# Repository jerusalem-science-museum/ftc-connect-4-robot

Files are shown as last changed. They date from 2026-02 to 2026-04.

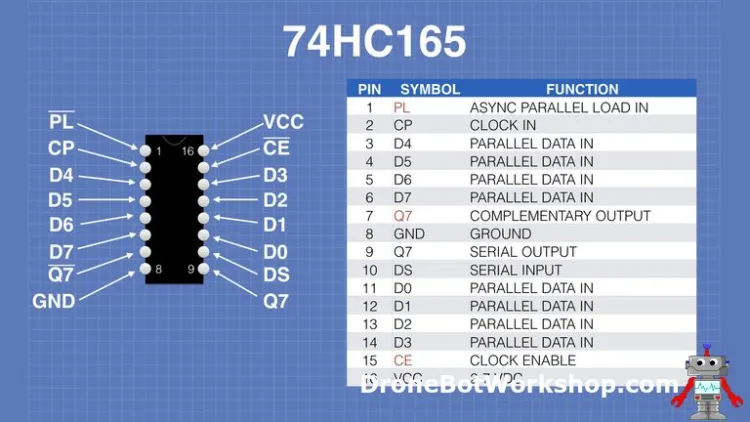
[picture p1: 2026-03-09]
docs/schematics and connections/piso 165.jpeg

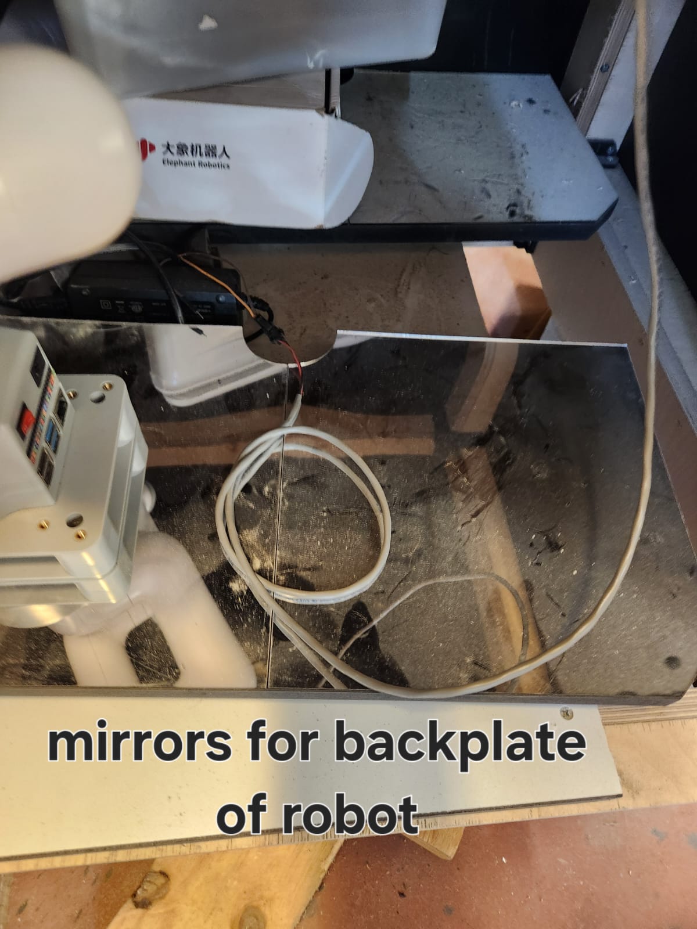
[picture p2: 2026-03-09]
docs/Photos/mirror for robot background.jpg

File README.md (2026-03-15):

# Connect 4 Robot

A robotic Connect 4 game where a MyCobot 280 robot arm plays against a human player. The system uses drop detection via LED strip sensors, automated puck dispensing with solenoids, and AI-powered gameplay.

## System Overview

```
┌───────────────────────────────────┐
│       PC MAIN CONTROLLER          │
│   ┌────────────┬────────────┐     │
│   │   Robot    │   Arduino  │     │
│   │ Interface  │ Interface  │     │
│   └────────────┴────────────┘     │
└─────────────┬──────┬──────────────┘
              │      │
        USB Serial   USB Serial
              │      │
     ┌────────▼─┐ ┌───▼────────────┐
     │  Robot   │ │   Arduino      │
     │  Arm     │ │ - LED Strip    │
     │  (via    │ | - Solenoids    │
     │pymycobot)│ │ - Sensors      |
     │          | | - Robot Pump   |
     └──────────┘ └────────────────┘
```

## Architecture

The system consists of three main controllers:

1. **PC Main Controller** - Orchestrates gameplay, runs AI, manages state
2. **Arduino Controller** - Handles LED strip, solenoid puck release, drop detection sensors, pump activation
3. **MyCobot 280 Robot Arm** - Picks and places pucks (using arduino pump), delivers pucks to player

## Key Components

### Game Logic (`game.py`)
- **Responsibilities**: Orchestrate turns, check win/draw, trigger robot moves
- **Event Handler**: `on_player_drop(column)` - called when Arduino detects puck
- **Flow**: Player drops → Update board → Check win → Calculate AI move → Execute robot → Repeat

### Board (`core/board.py`)
- **Responsibilities**: Store state, validate moves, detect wins
- **Pure Logic**: No hardware dependencies, easily testable
- **API**: `drop_piece()`, `is_valid_move()`, `check_win()`, `is_draw()`, `get_state()`

### AI Engine (`core/ai.py`)
- **Algorithm**: Minimax with alpha-beta pruning
- **Input**: Board state as 2D array
- **Output**: Best column to play (0-6)
- **Configurable**: Search depth adjustable via `config.yaml`

### Arduino Interface (`hardware/arduino.py`)
- **Responsibilities**: Serial communication, command sending, event callbacks
- **Commands**: `RELEASE:<col>`, `LED:[ON/OFF]`, `RESET`, `STATUS`
- **Events**: `DROP:<col>` (puck detected), `READY`, `ERROR:<msg>`
- **Thread Model**: Background listener thread for async event handling

### Robot Interface (`hardware/robot.py`)
- **Wrapper**: Clean API around legacy `ArmInterface.py`
- **Methods**: `place_puck_at_column(col)`, `give_player_puck()`, `move_to_home()`
- **Position Management**: Loads calibrated positions from `positions.json`

### Mock Hardware (`hardware/mock.py`)
- **Purpose**: Enable development/testing without physical hardware
- **Classes**: `MockArduino`, `MockRobot`
- **Usage**: Set `simulation: true` in `config.yaml`

## Setup

### Prerequisites

- **Hardware** (for production use):
  - MyCobot 280 robot arm (M5 Stack version)
  - Arduino with custom PCB (LED strip + solenoid drivers + sensors)
  - USB connections for both
  
- **Software**:
  - Python 3.8+
  - Arduino IDE (for firmware upload)

## How to Play

1. System initializes and robot moves to home position
2. Robot gives yellow puck to player at pickup location
3. Player drops puck in any column (detected by LED strip sensor)
4. PC calculates best move and robot executes (picks red puck, drops in column)
5. Robot returns and gives next yellow puck to player
6. Repeat until someone wins or board is full
7. System displays winner via XXX??? and resets for new game

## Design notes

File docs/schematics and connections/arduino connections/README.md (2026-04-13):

describes pin connections between components that are connected to the arduino.

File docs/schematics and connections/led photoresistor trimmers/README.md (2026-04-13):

# Photoresistor (LDR) trimmer board
A voltage splitter for identifying a voltage drop due to the puck blocking the light from the ledstrip.

can be used in multiple modes:  
1. using a potentiometer (what we did for now)
2. using constant-value resistors

IMPORTANT: the resistance we used for the detection in the end was **10Kohm.**

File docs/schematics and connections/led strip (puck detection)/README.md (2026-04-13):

# led strip for puck detection
Dual use pcb (depending on how and what you connect to it):
1. the leds on the one side that shine constant light, connect directly to 12v.  
2. the photoresistors (LDRs) on the other side that connects to the [trimmers](../led%20photoresistor%20trimmers) for sensing if the puck blocked the light from the leds.  

## General Specs
- total size - 360mmx7mm
- Each slot has pads for 0603, 2835, and TH type components.
- distance between adjacent components (leds/LDRs) - 51mm
- 2.1mm holes for tightening screws (though we just used glue), each 51mm apart.

## Connectors
- 

10 פינים בפסיעה של 1.25 מ"מ בצד הCS אפשר לחבר זוויתי או ניצב (סביר יותר).

פין 1 לפלוס, פין 2 למינוס, פין 3 (עתידי\רזרווה) מתחבר רק לאחד מפיני מולקס 2 פין

2 פינים פסיעה 2.54 (מולקס רגיל)  בקצה הכרטיס . פין אחד לפין 3 של קונקטור 10 פינים ואחד לאדמה – בעריכה עתידית צריך אולי לחבר לאדמה )

כי במידה ומשתמשים בקונקטור ה2 פין לכרטיס עם הלדים. צריך כרגע לגמפר ידנית את חיבור המינוס למולקס 2 פין

לדים מחוברים בשני זוגות בטור עם נגד ושלוש בטור עם נגד. גמפרים ונגדים בצד ה CS.

פלוס משותף לאנודות, מינוס לנגדים.

ערכי הנגדים לא בטוח ה 300 אוהם כמו שכתוב בשרטוט – לזוג לדים צריך נגד גדול יותר מאשר לשלישיה.

פוטוטרנזיסטורים- הפלוסים מחוברים פלוס דרך גמפרים (בצד ה PS) לפלוס. כל מינוס מחובר  בנפרד לפין נפרד בקונקטור בהמשך לנגד PD לאדמה מחוץ לכרטיס.  פינים 4-10 (כולל) בקונקטור.

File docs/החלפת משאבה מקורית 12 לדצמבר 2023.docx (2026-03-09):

12 לדצמבר 2023

המשאבה המקורית התקלקלה – בעיות במגעים\פחמים.

החלפתי למשאבה זעירה 5 וולט דגם Dp- שיש להו יותר מ110 כי יוסי קנה בטעות במקום ברזים חשמליים.

יש כרטיסון קטן המקבל פיקוד 5 וולט ומפעיל גם את המשאבה וגם ברז חשמלי לשחרור – חיבור הצנרת דרך מחבר T.

לא זוכר (וכנראה שכחתי לצלם\לרשום) את לוגיקת העבודה של הככרטיסון אבל נדמה לי שיש ממיר מתח קטן ומיקרו קטן אולי כדי לקבל גם פיקוד ב3.3 וולט מהאספרסיב.

אחרי שהמוצג עבד עם המשאבה החדשה התברר שהיא קצת חלשה מדי כי הדסקיות הצהובות (היותק עבות\כבדות) לא נתפסת טוב לפעמים.

הזמנתי משאבות חדשות ל 12 וולט ול 6 וולט (ינואר 2024 דרך יוסי) ובינתיים חיברתי שלוש משאבות קטנות במקביל עם מחבר X .

צריכת זרם לשלוש המשאבות במקביל (ב5 וולט) כ0.28 אמפר, כ0.09 אמפר למשאבה. בחיבור בקוטביות המקורית (חוט אדום לפלוס) הפיה השואבת היא הקרובה יותר לקצה ולא למרכז המלבן.

קוטר המיות של המשאבה כ3.1 מ"מ השתמשתי בצינור סיליקון מאינפוזיה ישנה של עדן 3/4 להכין טבעות מעבר לצינור סיליקון אקווריום 4/6. כדאי אבל טיפת דבק.

ווטסאפ אמיר לדקל 12 לדצמבר 2023

הכרטיס בסדר, מוציא 5 וולט. המשאבה תקולה ונראה שבעיה במגעים(קומוטטור/"פחמים") פנימיים כי כשקצת לוחצים מבחוץ מתחיל להסתובב. אבל חייבים להחליף כי זו תקלה של סוף אורך חיים בדרך כלל. במיידי יש לי משאבה ל5 וולט אבל הרבה יותר קטנה, צריך לוודא שמספיקה מבחינת קצב שאיבה. בהמשך כדאי להחליף למשאבה אמינה יותר, אבל תצטרך כנראה 12 וולט. יש לך מקור לספק אותו. אם לא והכל עובד על 5 וולט אפשר להכין כרטיסון ממיר קטן. וגם נצטרך כראיס מיתוג אחר. דבר איתי

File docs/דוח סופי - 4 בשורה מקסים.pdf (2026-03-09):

# המחלקה להנדסת מכונות

# פיתוח מוצג אינטראקטיבי המדגים פעולה רובוטית על ידי משחק "ארבע בשורה"

# מאת מקסים מז'ביין

## מנחה אקדמי: ד"ר מחמוד ספדי מנחה מקצועי: ד"ר אמיר בן שלום

## 04/09/2025 י' אלול תשפ"ה

# הצהרה

## העבודה נעשתה בהנחיית ד"ר אמיר בן שלום, בארגון "מוזיאון המדע

ע"ש בלומפילד ירושלים", ובהנחיית ד"ר ספדי מחמוד, עזריאלי מכללה אקדמית להנדסה ירושלים, המחלקה להנדסת מכונות.

## החיבור מציג את עבודתי האישית

ומהווה חלק מהדרישות לקבלת תואר ראשון בהנדסה.

## כל טקסט ו/או תוצאה המבוססים על עבודות מחקר אחרות, מתועדים

בציון המקור המדעי.

## תקציר

הפרויקט עוסק בתיקון מוצג במוזיאון המדע שבו המבקר משחק את משחק הקופסא "ארבע בשורה" מול זרוע רובוטית.

המוצג דורש תיקון מכיוון שהוא השתמש בראייה ממוחשבת לקליטת מצב הלוח, מערכת שכשלה לעיתים קרובות ועשתה את המוצג בלתי שמיש ולכן המוצג הורד מרחבת המוזיאון.

הפרויקט מתמקד בפיתוח מערכת המבוססת על חיישנים אלקטרוניים לקליטת נפילת דסקיות בעמודות הלוח.

הדוח הנוכחי מציג את הפתרון המוצע המבוסס על חיישני אור אלקטרוניים, המאפשרים זיהוי אמין של נפילת הדסקיות בעמודות הלוח. בדוח מוצגים כל השלבים והניסויים: החל מבחירת החיישן המתאים )פוטורזיסטור( וקביעת ערך הנגד במחלק המתח, דרך בחירת צבע LED אופטימלי, ועד פיתוח פרוטוקול תקשורת בינארי ייעודי בין בקר החיישנים למחשב המפעיל את הזרוע. לבסוף מתוארים השיקולים ההנדסיים ואופן ההתקנה הסופי של החיישנים על לוח המשחק.

# תוכן עניינים

תקציר 2 |
.1 מבוא5 |
.2 רקע תיאורטי6 |
.2.1 ארבע בשורה 6 |
.2.2 הזרוע הרובוטית - 5M280 MyCobot6 |
.2.3 חוק אוהם 8 |
.2.4 חוק קירכהוף לזרם - KCL8 |
.2.5 חוק קירכהוף למתח - KVL9 |
.2.6 מחלק מתח9 |
.2.7 מיקרו בקרים - 32ESP & Arduino10 |
.2.8 אוגר זיזה - Register Shift11 |
.2.9 חיישני אור - פוטורזיסטורים12 |
.2.10 ביטים, בייטים וייצוג בינארי14 |
.3 מטרות 15 |
.4 חקר המצב הקיים 16 |
.4.1 המצב הקיים 16 |
.4.2 חקר המצב הקיים - תקלות ובעיות 18 |
.4.3 ניתוח חוזק הזרוע לאימות התקנה אופקית 18 |
.5 מתודולוגיות21 |
.5.1 להישאר עם ראיה ממוחשבת 21 |
.5.2 פתרון אלקטרוני מבוסס חיישנים22 |
.5.3 המתודולוגיה שנבחרה 24 |
.6 יישום ופיתוח הפתרון 24 |
.6.1 חישוב זמן חסימת החיישן על ידי דיסקית נופלת 24 |
.6.2 בחירת הלד המתאים28 |
.6.3 בחירת הנגד המתאים למחלק המתח 31 |
.6.4 שילוב עם המיקרו בקר33 |
.6.5 תכנון פרוטוקול התקשורת 35 |
.6.6 עיצוב התוכנה38 |
.6.7 מידול הפתרון41 |
.7 תוצאות44 |
.8 תכנון מול ביצוע45 |
.9 ביבליוגרפיה46 |
.10 נספחים 47 |
.10.1 תרשים GANTT 47 |
.10.2 תרשים WBS 48 |
.10.3 קוד פרוטוקול התקשורת בC לבניית בייט ההודעה48 | :
.10.4 הקוד בפייתון ליצירת ופיענוח הודעה: 49 |
.10.5 הקוד לשליחת הודעה, והמתנה לאישור בפייתון49 | :

# תוכן איורים

איור #1 - לוח ארבע בשורה6 |
איור #2 - מערכת הקואורדינטות של הזרוע הרובוטית 7 |
איור #3 - מעגל חשמלי פשוט 9 |
איור #4 - דיאגרמת פינים של 165HC74 12 |
איור #5 - מחלק מתח עם פוטורזיסטור13 |
איור #6 - גרף מחלק מתח14 |
איור #7 - מבט איזומטרי של המוצג 16 |
איור #8 - מבט מהצד הפנימי של המוצג 17 |
איור #9 - הזרוע במצב התקנה אופקי, עם מפרקים ממוספרים19 |
איור #10 - הזרוע במצב התקנה אנכי, כאשר המפרק 1J מסובב ב.90° 19 |
איור #11 - דג"ח על הזרוע 21 |
איור #12 - דג"ח של דיסקית בנפילה חופשית25 |
איור -#13 הגדרת פרמטר d של הדיסקית הנופלת 25 |
איור #14 - גרף של זמן נפילת דיסקית עם מהירויות התחלתיות שונות27 |
איור #15 - מערכת הניסוי לבחירת צבע לד28 |
איור #16 - גרף תוצאות ניסוי בחירת צבע לד30 |
איור #17 - השפעת נגד קבוע במחלק מתח31 |
איור #18 - מעגל הניסוי לקביעת ערך נגד קבוע32 |
איור #19 - אוגר זיזה מחובר לבקר הזרוע34 |
איור #20 - דיאגרמת התקשורת בין המחשב לבקרים השונים35 |
איור #21 - דיאגרמה של המודולים של התוכנה38 |
איור #22 - תרשים הזרימה של לוגיקת המוצג 39 |
איור #23 - תיאור מפורט של שלבי התוכנה40 |
איור #24 - מידות הפאנל הקדמי 41 |
איור #25 - שרטוט ממדי רצועת הלדים42 |
איור #26 - שרטוט ממדי רצועת החיישנים 42 |
איור #27 - שרטוט התעלה שבה תותקן רצועת הלדים בצד הפנימי של הפאנל הקדמי 42 |
איור #28 - שרטוט התעלה שבה תותקן רצועת רצועת החיישנים43 |
איור #29 - התקנת הרצועות החיישנים במוצג הסופי44 |

# תוכן טבלאות

טבלה #1 - פרמטרי DH של הזרוע הרובוטית7 |
טבלה #2 - תוצאות ניסוי בחירת צבע לד30 |
טבלה #3 - תוצאות ניסוי בחירת נגד קבוע33 |
טבלה #4 - מבנה בייט התקשורת36 |

## .1 מבוא

הפרויקט נעשה עבור ובשיתוף עם מוזיאון המדע בירושלים - "מוזיאון המדע ע"ש בלומפילד ירושלים".
מוזיאון המדע מציג מגוון מוצגים אינטראקטיביים שנועדו להמחיש עקרונות מדעיים וטכנולוגיים לקהל הרחב, תוך דגש על התנסות אישית וחווייתית. אחד מהמוצגים שנבנו בעבר נועד להדגים עקרון של הפעלת זרוע רובוטית לצורך משחק "ארבע בשורה" מול המשתמש. במוצג זה המשתמש מפיל דסקיות לתוך לוח אנכי, והמערכת אמורה לזהות את מיקום ההפלה, לעדכן את מצב הלוח, ולשלוט בזרוע הרובוטית כדי לדמות שחקן שני ולאתגר את המשתמש.

עם זאת, המוצג המקורי לא תפקד בצורה מספקת, מערכת הזיהוי שהתבססה על ראייה ממוחשבת לא הצליחה לזהות בצורה אמינה את מיקום הדסקיות, ובגלל זה גם לא הצליחה לעשות מהלכים שיאתגרו את המשתמש. בעיות אלו נבעו בין השאר מתנאי תאורה משתנים, צבעי בגדים של המשתמשים, וחוסר עקביות בקריאות החיישנים. כתוצאה מכך המוצג הוסר מהתצוגה עד שיתוכנן מנגנון חדש לזיהוי מיקום הדסקיות של המשתמש.

מטרת פרויקט זה היא להחזיר את המוצג לפעולה על ידי תכנון מנגנון שיקלוט את מיקום הפלת הדיסקית של המשתמש באופן אמין ועקבי, וכתוצאה מכך ייתן אתגר למשתמש, ללא צורך בתחזוקה קבועה או התערבות מפעיל.

הדוח הנוכחי מציג את שלבי הפרויקט מהגדרת הבעיה ועד לפתרון. לאחר פרק המבוא, מובא רקע תיאורטי הכולל את המידע הטכני הדרוש להבנת הפתרון שנבנה. בהמשך מפורטות מטרות הפרויקט, מתודולוגיות שונות שנשקלו לפתרון הבעיה, ותהליך בחירת הפתרון. לאחר מכן מתוארים הניסויים שבוצעו ותוצאותיהם, תהליך היישום של המערכת בפועל, והמסקנות שהוסקו מהתהליך. בסוף הדוח מופיעה רשימת מקורות ונספחים טכניים.

## .2 רקע תיאורטי

## .2.1 ארבע בשורה

ארבע בשורה הינו משחק לוח בין שני שחקנים , שמשוחק על לוח אנכי בעל 7 טורים ו6- שורות. השחקנים לוקחים תורות בהפלת דסקיות אל תוך העמודות במטרה להגיע לרצף של 4 דיסקיות בצבע שלהם. תנאי הניצחון הוא רצף של ארבע דסקיות באלכסון , טור או שורה )בתמונה 1 רואים מצב לוח בו השחקן עם הדיסקיות הצהובות ניצח באמצעות רצף אלכסון(. שוויון קורה כאשר הלוח מתמלא בלי שנוצר רצף של 4 דיסקיות לאף שחקן. ב1988 הוכח שארבע בשורה הוא משחק "פתור", משחק פתור זהו משחק שמכל מצב אפשרי שלו אפשר לחשב את רצף המהלכים המדויק שיוביל לניצחון - זאת אומרת שהשחקן המתחיל תמיד יכול לנצח או להגיע לשוויון, אך אף פעם לא להפסיד )1988 ,Allis).

איור #1 - לוח ארבע בשורה

## .2.2 הזרוע הרובוטית - 5M280 MyCobot

הזרוע הרובוטית שבה יהיה שימוש בפרויקט היא הזרוע 5M280MyCobot, מבית Elephant .Robotics
זוהי זרוע עם 6 דרגות חופש, המופעלת באמצעות בקר מסוג 32ESP, דרך מערכת ה-Stack 5M -המשלבת מעבד, תצוגה וחיבורים מובנים. הזרוע מתקשרת עם המחשב דרך USB, ומופעלת ע"י שפת התכנות פייתון. אחת המגבלות של המערכת היא קצב התקשורת הנמוך יחסית, הנובע ממעבר בין מספר שכבות תקשורת )כולל פרוטוקולים פנימיים של USB, תרגום פקודות, ועיבוד בפייתון(, דבר המגביל את זמן התגובה של הזרוע לבקשות חיצוניות - עובדה שהתגלתה בניסויים שיצויינו בהמשך הדוח.

הזרוע מסוגלת להרים עד 250 גרם, ורדיוס עבודה של mm.280 לצורך שליטה מדויקת במיקום קצה הזרוע, נעשה שימוש בפרמטרי DH) Hartenberg-Denavit) שמתארים את הגיאומטריה של הזרוע ואת יחסי המיקום בין כל מפרק. פרמטרי הDH של הרובוט נתונים בתמונה .#2
חברת Robotics Elephant מציע ספריות פייתון בכדי לשלוט בזרוע, הכוללות פונקציות לחישוב קינמטיקה הפוכה, המאפשרות לחשב את ערכי הזוויות של כל אחד מהמנועים כדי שקצה הזרוע יגיע לנקודה הרצויה במרחב, תוך התחשבות במגבלות מכניות, מגבלות מומנט, והימנעות מהתנגשות עצמית.
)Elephant Robotics, 2021(

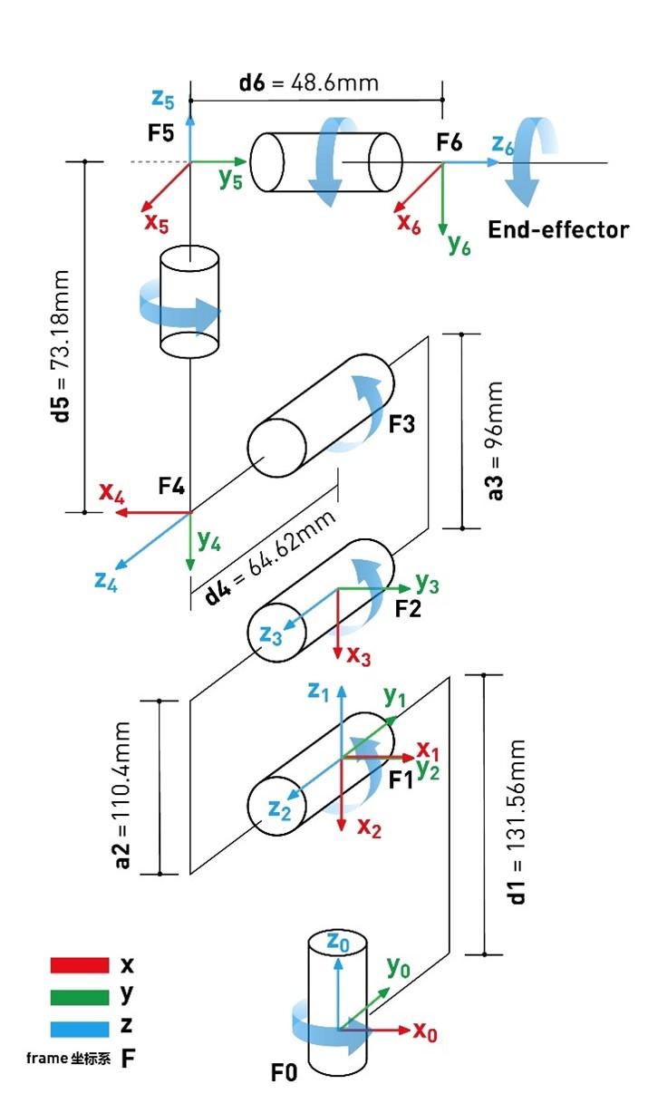
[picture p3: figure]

איור #2 - מערכת הקואורדינטות של הזרוע הרובוטית

| α [DEG] | A [mm] | D [mm] | θ [DEG]
1 | 0 | 0 | 131.56 | θ 0
2 | 90 | 0 | 0 | θ 1
3 | 0 | -110.4 | 0 | θ 2
4 | 0 | -96 | 64.62 | θ 3
5 | 0 | 0 | 73.18 | θ 4
6 | -90 | 0 | 48.6 | θ 5

טבלה #1 - פרמטרי DH של הזרוע הרובוטית

## .2.3 חוק אוהם

חוק אוהם הוא אחד מחוקי היסוד בחשמל ובאלקטרוניקה, והוא מתאר את הקשר בין המתח, הזרם, וההתנגדות במעגל ורכיב חשמלי. חוק אוהם מראה את הקשר הלינארי הקיים בין המתח, לזרם וההתנגדות:

כאשר:
V - מתח, נמדד בוולט ]V]
I - זרם, נמדד באמפר ]A]
R - התנגדות, נמדד באוהם ]Ω]

בחוק אוהם שימוש נרחב במעגלים חשמלים בכדי לקבוע את הפרמטרים השונים הנדרשים להפעלת רכיבים, כגון זרם לנורת לד, או התנגדות כדי להגביל את המתח על רכיב מסויים.

## .2.4 חוק קירכהוף לזרם - KCL

חוק קירכהוף לזרם הידוע גם כ"חוק הראשון של קירכהוף", מתאר את עקרון שימור המטען החשמלי במעגלים חשמליים. החוק קובע כי סכום הזרמים הנכנסים לצומת במעגל חשמלי שווים לסכום הזרמים היוצאים ממנה - לא קורה איבוד של זרם.

)2.4.1(

k=1

n
∑ I

k = 0

כאשר מסתכלים על צומת במעגל חשמלי: - הזרם על ענף ה-k בצומת.
k
n - מספר הענפים בצומת.

נהוג לקבוע את כיוון הזרמים בתחילת הניתוח של המעגל החשמלי ובמקרה של זרמים שליליים סימן שהכיוון הראשוני היה הפוך.

V = RI | )2.3.1(

## .2.5 חוק קירכהוף למתח - KVL

חוק קירכהוף למתח הידוע גם כ"חוק השני של קירכהוף", מתאר עקרון בסיסי במעגלים חשמלים.החוק קובע כי סכום כל המתחים בלולאה סגורה במעגל חשמלי הוא לאפס. חוק זה מבטא את עיקרון שימור האנרגיה במעגל חשמלי.

)2.5.1(

k=1

n
∑ V

k = 0

כאשר מסתכלים על לולאה סגורה במעגל חשמלי: - המתח על הרכיב ה-k בלולאה.
k
n - מספר הרכיבים בלולאה.

## .2.6 מחלק מתח

מחלק מתח הוא כלי בסיסי לניתוח במעגלים חשמליים, המאפשר לחשב את המתח על פני רכיב מסוים, או לחלופין - לייצר מתח נמוך יותר מתוך מתח כניסה נתון. השיטה מבוססת על חיבור שני נגדים או יותר בטור, כך שהמתח מתפלג ביניהם בהתאם לערכם. ניקח את המעגל הפשוט המתואר באיור :3

איור #3 - מעגל חשמלי פשוט

מתוך חוק קירכהוף הראשון, במעגל טורי הזרם הנופל על כל הרכיבים זהה כלומר הזרם על כל אחד מהנגדים זהה, ומחוק קירכהוף השני סכום המתחים על פני הרכיבים במעגל סגור שווה למתח המקור.
באמצעות חוקי קירכהוף וחוק אוהם אפשר להראות שבמעגל טורי ההתנגדות הכוללת היא סכום הנגדים במעגל:

∑ V= V

in − V

1 − V

2 = 0 ⇒ V

in = V

1 + V
2

⇒ IR

total = IR

1 + IR
2

⇒ R

total = R

1 + R
2

ולכן בשילוב עם חוק אוהם על המעגל הכולל:

V

in = R
total

I = (R

1 + R
2

) · I ⇒ I =

V
in
R

1+R
2
ואם נפעיל את חוק אוהם שוב רק על נגד :1

V

1 = IR
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
קיבלנו ביטוי כללי למחלק מתח עבור שני נגדים, אפשר להכליל זאת עבור כל מספר של נגדים בטור:

)2.6.1(

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
כאשר:
- המתח על רכיב n.
n
- ההתנגדות של רכיב n.
n
- מקור המתח.
in
k - מספר הרכיבים במעגל

## .2.7 מיקרו בקרים - 32ESP & Arduino

מיקרו-בקר הוא רכיב אלקטרוני הכולל על גבי שבב יחיד מעבד, זיכרון, וממשק של קלט ופלט. מיקרו בקרים משמשים לשליטה על מערכות משובצות מחשב - מערכות הפועלות בצורה אוטונומית כחלק ממכשירים פיזיים.
משתמשים במיקרו בקרים בשביל מספר דברים: .1 לקלוט קלט ממספר חיישנים למיניהם כפתורים, או רכיבים אנלוגים. .2 לעבד מידע חיצוני שנקרא דרך החיישנים לפי תוכנה שהוטענה בו מראש. .3 להפעיל רכיבים חיצונים המחוברים אליו כגון מנועים, לדים ותצוגות. יש שימוש רב במיקרו בקרים בפרוייקטים הדורשים שילוב מסויים של תוכנה עם חומרה.

Arduino היא פלטפורמה לפיתוח מערכות משובצות והתכנות בה מתבצע דרך שימוש בשפת C. לוח הארדואינו שיהיה בו שימוש בפרויקט הוא מסוג UNO Arduino.

32ESP הוא מיקרו בקר מתקדם, המשמש כיחידת העיבוד המרכזית של הזרוע הרובוטית, וביצוע החישובים הדרושים.
ה־32ESP משולב בתוך הזרוע כחלק מפלטפורמת ה-Stack 5M שהיא פלטפורמה מודולריות הכוללת מסך ממשקי תקשורת וחיבורים נוחים לרכיבים חיצוניים המייעלת את העבודה עם הבקר. לפי הקושחה הקיימת על הבקר, התכנות בו נעשה דרך שפת פייתון, שפה זו מאפשרת פיתוח מהיר ונוח לעומת C, אך היא גם גורמת לעומס עיבוד ולהאטה בקצב התקשורת עם הבקר, במיוחד כאשר יש צורך בעיבוד נתונים בזמן אמת.

בארדואינו וב32ESP נעשה שימוש בפינים דיגיטלים ואנלוגים לחיבור חיישנים ורכיבים שונים. הפינים הדיגיטליים מזהים שני מצבים בלבד - HIGH ו-LOW, כאשר ההבחנה נקבעת לפי המתח הפועל על הפין.
עבור לוחות ארדואינו מתח הסף לHIGH הוא V,3 ועבור לוחות 32ESP מתח הסף הוא כV.2.475 )ARDUINO, 2024) (Espressif Systems, 2016(

## .2.8 אוגר זיזה - Register Shift

בפרויקט נעשה שימוש במספר רב של חיישנים ורכיבים, אך מספר הפינים לחיבור אותם חיישנים ורכיבים הזמינים על גבי הבקרים מוגבל. כדי להרחיב את מספר הקלטים והפלטים על הבקר נעשה שימוש ברכיבי Register Shift או אוגרי זיזה, המאפשרים תקשורת טורית)או מקבילית( עם רכיבים מרובים תוך שימוש במספר קטן של פינים. אוגר זיזה הוא רכיב דיגיטלי המאפשר המרה של מידע טורי למקבילי, ומקבילי לטורי, והם ניתנים לשרשור זה עם זה בשביל הרחבה בלתי מוגבלת.

קיימים שני סוגים של אוגרי זיזה:

: | ממקבילי | טורי | קלט - Parallel in serial out .1
register Shift זה )מסוג 165HC74 )משמש לקריאת מספר חיישנים המחוברים לקווי הקלט המקבילים של רכיב )רגליים H-A, בתמונה #4(. ברגע שניתנת פקודת טעינה )ברגל 1(, הרכיב לוכד את הערכים מכל הקווים H-A, ואז משדר אותם זה אחר זה עם כל הפעלת )פולס( השעון )רגל 2( דרך קו אחד )רגל 9(.

באופן זה ניתן לקרוא 8 חיישנים דרך פין אחד בלבד, במקום 8 פיני קלט נפרדים בבקר. )Texas Instruments, 2015(

איור #4 - דיאגרמת פינים של 165HC74

: | מטורי | מקבילי | פלט - Serial In Parallel out .2
register Shift זה )מסוג 595HC74), דומה לאוגר הזיזה הטורי אך בכיוון ההפוך: הוא מקבל מידע טורי )סדרה של ביטים( דרך כניסה אחת, וממיר אותו לפלט מקבילי על פני 8 יציאות.
באופן זה ניתן להפעיל מספר רב של מנועים, סולנואידים או רכיבים אחרים תוך שימוש במספר מצומצם של פינים בבקר. )Texas Instruments, 2021(

## .2.9 חיישני אור - פוטורזיסטורים

פוטורזיסטור הוא חיישן פסיבי המשנה את התנגדותו בהתאם לכמות האור הפוגעות בו, בניגוד לנגד משתנה מכני )פוטנציומטר(, שינוי ההתנגדות של הפוטורזיסטור מתבצע באופן אוטומטי בהתאם לתנאי הסביבה.

כאשר עוצמת האור גבוהה - התנגדות החיישן יורדת ושואפת לאפס. כאשר עוצמת האור נמוכה התנגדות החיישן עולה מאוד )עד לאזור הMΩ). התנהגות זו מאפשרת קריאת תנאי תאורה בסביבה. דרך נפוצה לעבוד עם פוטורזיסטור היא באמצעות שימוש מחלק מתח, ומדידת המתח הנופל עליו, על ידי התקנת החיישן בטור עם נגד קבוע.

איור #5 - מחלק מתח עם פוטורזיסטור

במערכת המתוארת באיור 5 הפוטורזיסטור מסומן בRp, והמתח הנופל עליו, על פי עקרון מחלק המתח )נוסחה 2.6.1( הוא:

V

Rp =

R
p
R

1+R
p
- V
in

אפשר לראות שככול שנופל יותר אור על החיישן התנגדותו תרד ותשאף לאפס, מה שיגרום לרוב המתח ליפול על 1R ולאיפוס המתח על פני החיישן. לחלופין אם אין הרבה אור, התנגדות החיישן תגדל מה שיגרור מתח יותר גבוה על הרכיב, והוא יקבל את רוב מתח הספק.
אפשר לראות בגרף המצורף איך המתח על פני הפוטורזיסטור משתנה עם ההתנגדות שלו, הגרף מתאר מחלק מתח עם מקור מתח של V,5 ונגד קבוע עם ערך של kΩ,2 כאשר ציר X זה התנגדות הפוטורזיסטור, וציר Y המתח עליו.

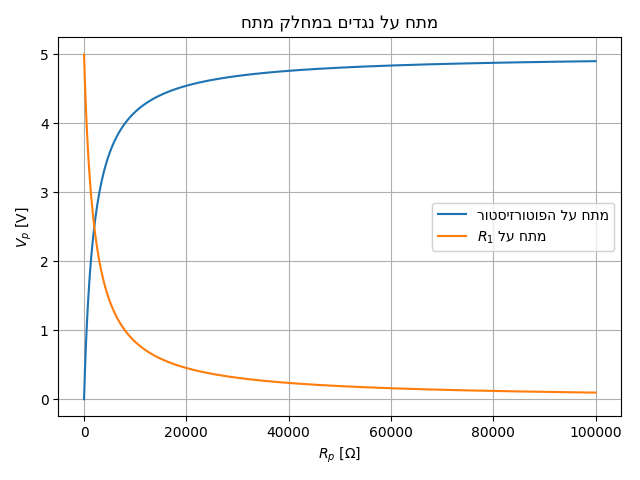
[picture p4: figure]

איור #6 - גרף מחלק מתח

מהגרף אפשר לראות שככול שההתנגדות של הפוטורזיסטור עולה )החיישן מקבל פחות אור(, המתח הנופל עליו שואף ל-V,5 ולהפך - ככל שהחיישן מקבל פחות אור, ההתנגדות עליו יורדת, ולכן המתח עליו מתקרב לאפס, ובנוסף על פי חוק קירכהוף למתח אפשר גם לראות שהמתח על הנגד השני תמיד משלים את סכום המתחים למתח הכניסה של V.5

## .2.10 ביטים, בייטים וייצוג בינארי

במערכות דיגיטליות מידע מיוצג באמצעות מצבים חשמליים: מתח גבוה )1( ומתח נמוך )0(, מצב כזה נקרא ביט )סיבית(, ומערכת המבוססת על ביטים נקראת מערכת בינארית.

כאשר יש קבוצת ביטים ביחד מתקבל מספר בבסיס ,2 שבו המיקום של כל ספרה )0/1( מייצג את החזקה של 2 שמוסיפים לערך הסופי על פי הנוסחה הבאה:

Val

10 =
i=0

n−1
∑ b
i
- 2

i

כאשר:
n = מספר הספרות במספר הבינארי. i = מיקום הספרה במספר הבינארי. bi = הספרה במספר הבינארי במיקום ה-i. 10Val = המספר בבסיס 10 )דצימלי(.

לדוגמא:

(1101)

2 = 1 · 2

3
+ 1 · 2

2
+ 0 · 2

1
+ 1 · 2

0 = (13)
10

צירוף של 8 ביטים יוצר בייט )256 מצבים אפשריים(, זהו גודל המידע המינימלי שבו מחשבים קוראים וכותבים לזיכרון, וכן יחידת-הבסיס ברוב פרוטוקולי התקשורת.

## .3 מטרות

המטרות הממוקדות של הפרויקט הן: .1 פיתוח מנגנון זיהוי אמין למיקום הפלת הדיסקית של המשתמש, שלא תלוי בגורמים חיצונים, ומהווה תחליף מלא למנגנון הראיה הממוחשבת הקיים. .2 בחירה ותכנון נכון של מערכת החיישנים, הכולל מיקום התקנה מתאים, ורכיבים מתאימים כדי להשיג את הנאמר בנקודה .1 .3 כתיבת תוכנה של הבקר שתיקח את כל המידע מהחיישנים בזמן אמת, ותשתמש בו כבסיס לאלגוריתם שיריץ את המשחק.
.4 אינטגרציה מלאה בין המערכת החדשה לישנה באופן כזה שיראה שהפתרון החדש היה הפתרון המקורי.
.5 הבטחת אמינות גבוה של המוצג, שלא יכשל או ידרוש מעורבות מפעיל, במשך מאות השעות שיעבוד במוזיאון באופן רציף ויהיה חשוף למבקרי המוזיאון. .6 יישום אלגוריתם משחק שיאתגר את המשתמש, וינצח את המשתמש או לפחות יגיע תמיד לשוויון, ויעניק חוויית אתגר אמיתית.

ממדי ההצלחה למטרות אלה הינן: .1 התוכנה תדע בכל רגע נתון, באמינות של 100% את מצב הלוח בפני המשתמש - סממן שהחיישנים עובדים והמערכת החדשה הוטמעה היטב עם המערכת הישנה. .2 הפעלה של המוצג במשך עשרות שעות ללא התערבות מפעיל וללא זמני השבתה. .3 הזרוע הרובוטית תמיד מנצחת או משיגה שוויון מול המשתמש, סימן לכך שהאלגוריתם יציב ואפקטיבי.

## .4 חקר המצב הקיים

## .4.1 המצב הקיים

בחקר המצב הקיים נתמקד באופן פעולת המוצג לפני תחילת הפרויקט, ולאחר מכן ננתח את הבעיות הקיימות בו.

ניתן לפרק את פעולת המוצג לשלושה חלקים עיקריים:
- הבאת דיסקית למשתמש
- מיון דיסקיות בסוף המשחק
- התוכנה השולטת
לשם הבנה קלה יותר של הפרק, מצורף באיור #7 שרטוט המוצג.

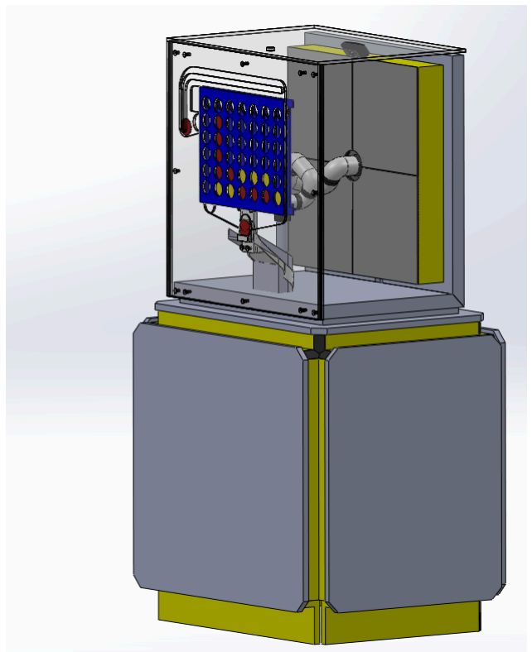
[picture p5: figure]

איור #7 - מבט איזומטרי של המוצג בבסיס אזור המשחק קיים בנק דיסקיות בשני צבעים, אחד לרובוט ואחד למשתמש, כאשר הרובוט מרים דסקית באמצעות משאבת ואקום.

אם התור העכשווי שייך לרובוט הזרוע מפילה את הדיסקית לאחד מ7- העמודות בלוח דרך חורים בצד הפנימי של המוצג. אם התור העכשווי שייך למשתמש אז הזרוע מפילה את הדיסקית לתוך תעלה עליונה שממנה המשתמש גורר את הדיסקית באמצעות האצבע דרך תעלה העוברת מעל שבעת הטורים ומפיל את הדיסקית בעמודה הרצויה, כפי שאפשר לראות באיור .#8

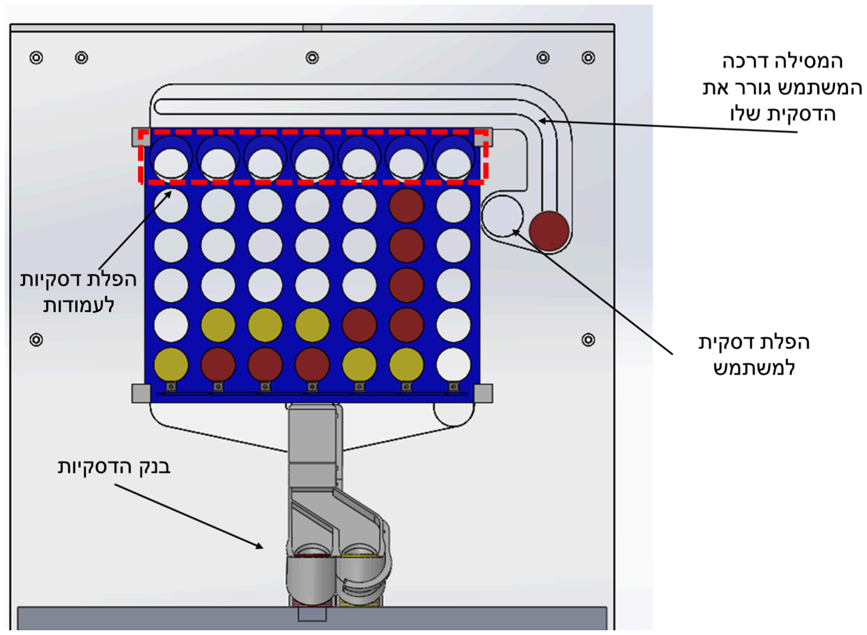
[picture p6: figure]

איור #8 - מבט מהצד הפנימי של המוצג

כדי להשאיר את הדיסקיות במקום קיימים סולנואידים בבסיס כל עמודה המחזיקים את עמודת הדסקיות מעליה, בשביל מיון הדסקיות בסוף המשחק הסולנואידים נפתחים בזה אחר זה ומפילים את הדיסקיות אל מסילה.
במסילה קיים חריץ בעובי 3.5 מ"מ: דיסקיות האדומות יש עובי של 3 מ"מ ולכן הן נופלות דרך החריץ ומנותבות למאגר האדום. דיסקיות הצהובות יש עובי של 4 מ"מ, הן לא מסוגלות לעבור בחריץ ולכן ממשיכות במסילה עד שמגיעות למאגר הצהוב, כפי שאפשר לראות באיור .#8

לצורך קליטת מצב הלוח נעשה שימוש בראייה ממוחשבת. בכל אחת מארבע פינות הלוח מודבק סמן Aruco. מצלמת רשת מצלמת את הלוח בזמן אמת, והסממנים משמשים כנקודות עיגון לזיהוי גבולות הלוח. אלגוריתם עיבוד תמונה מזהה את הדיסקיות בתוך אזור המשחק, מעדכן את מצב הלוח בזיכרון, ומחשב את מהלכי המשחק. האלגוריתם שמשחק מול המשתמש מבוסס על מודל פשוט של למידת מכונה, ונועד לייצר אתגר מסוים לשחקן האנושי.

למיקרו בקר של הזרוע מחובר באופן ישיר אוגר זיזה מסוג 595HC74 בכדי לשלוט בשבעת הסולנואידים,מחוברת המשאבה לשליטה על הואקום, ומחובר הכפתור שמתחיל את המשחק.

## .4.2 חקר המצב הקיים - תקלות ובעיות

רכיבי ההרמה, ההפלה והמיון של הדסקיות פעלו באופן אמין ויציב לאורך זמן. לעומתם, מערכת זיהוי מצב הלוח, שהתבססה על ראייה ממוחשבת כשלה בזיהוי עקבי ואמין של מהלכי המשתמש.

מערכת הזיהוי לא פעלה באופן מדויק. היא הייתה רגישה מאוד לשינויים בתנאי תאורה, ולצבעי בגדים של המשתמשים )במיוחד כאשר צבע הבגד היה דומה לצבע הדיסקית(. כתוצאה מכך נוצרו זיהויים שגויים או חוסר זיהוי כלל.

בנוסף אלגוריתם המשחק לא יצר חוויית אתגר אמיתית, ככל הנראה משתי סיבות:
- הוא מבוסס על מודל פשוט של למידת מכונה, ללא עומק אסטרטגי.
- הוא עבד על סמך נתונים לא מדויקים מהזיהוי החזותי.

בעקבות ליקויים אלה, המוצג הוסר מרחבת התצוגה והועבר לאחסון, עד לפיתוח פתרון חלופי. לא קיימים נתונים מדויקים על אחוזי הכשלונות, אך ידוע שהאמינות לא הגיעה ל־,100% ולכן המוצג לא נמצא מתאים להצגה במצבו הקיים.

## .4.3 ניתוח חוזק הזרוע לאימות התקנה אופקית

הזרוע הרובוטית נועדה לעבוד באופן אנכי, כך שהבסיס עומד על גבי משטח אופקי. במוצג המוזיאון הזרוע מותקנת באופן אופקי כך שהבסיס מותקן על גבי קיר אנכי והזרוע יוצאת ממנו באופן אופקי. התקנה זו מוסיפה כוחות ומאמצים שהיצרן לא בהכרח לקח בחשבון כאשר הוא אמר שהזרוע מסוגלת להרים 250 גרם, ויש אפשרות שהמנועים שהייצרן בחר לא יעמדו בעומסים החדשים המתקבלים להתקנה אופקית.

בזרוע קיימים שישה מפרקים )5J0-J), כאשר כל מנוע תומך במשקלו העצמי של הזרוע ובמשקל המנועים שמעליו. כפי שניתן לראות בתמונות #9 ו,#10- המצב הגיאומטרי שבו הזרוע מותקנת אופקית זהה לחלוטין למצב שבו הזרוע מותקנת אנכית והמפרק הראשון )1J )מסובב ב.90°- במקרה זה, המפרקים 5J1-J נמצאים באותם מיקומים יחסית לכבידה, ולכן חווים את אותם מומנטים ומאמצים בדיוק.

מכאן ניתן להסיק כי עבור המפרקים 5J1-J אין שינוי בעומסים, והתקנה אופקית לא יוצרת מאמץ נוסף בהשוואה למצב האנכי שתוכנן על ידי היצרן. לכן, אם היצרן מציין שהזרוע יכולה להרים עד 250 גרם מכל מצב תנועה אפשרי הנחה זו נותרת תקפה גם עבור התקנה אופקית, כל עוד הכוונה היא לעומסים על מפרקים 5J1-J.

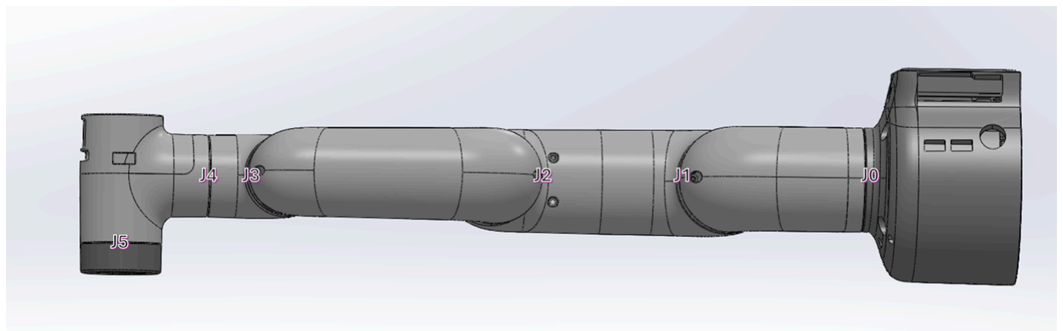
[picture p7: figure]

איור #9 - הזרוע במצב התקנה אופקי, עם מפרקים ממוספרים

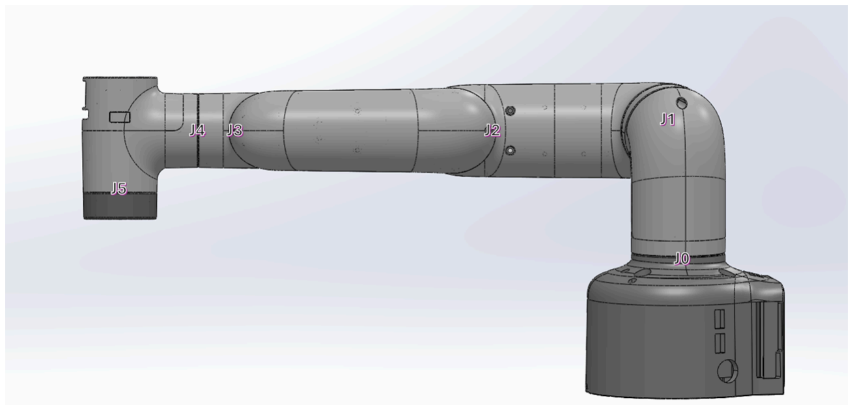
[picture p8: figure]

איור #10 - הזרוע במצב התקנה אנכי, כאשר המפרק 1J מסובב ב.90°

לעומת זאת, מפרק הבסיס )0J )הוא החריג, בתצורה האנכית הוא רק מסובב את הזרוע במישור אופקי, אך בתצורה האופקית הוא נדרש לשאת את משקל הזרוע כולה, ולכן יכולים להיווצר מאמצים שונים בהשוואה להתקנה תקנית, לכן כאשר ננתח את המאמצים על הזרוע, נבדוק רק במפרק הבסיס 0J.

לשם הניתוח של הזרוע הזרוע הרובוטית נדרש לעשות מספר השערות:
- מכיוון שהזרוע היא מערכת דינמית, מרכז הכובד משתנה בהתאם לזוויות הפרקים השונים, לשם הקלת הניתוח ניקח את המצב המחמיר ביותר בו מרכז הכובד הכי רחוק מבסיס הזרוע, ובזמן שפועל מומנט מקסימלי מהמשקל בסוף הזרוע על מנוע הבסיס, ואם הזרוע תחזיק במצב זה, היא תחזיק בכל מצב אחר.
- משקל הזרוע כולה 850 גרם, אך אנחנו לא רוצים את משקל הזרוע כולה, רק ממפרק 1J והלאה, לאחר פירוק הזרוע ושקילתה רק ממפרק 1J נמצא שהמשקל העצמי של חלק זה הוא 515 גרם.
- משקל הדיסקית הכבדה ביותר שהזרוע תרים הוא 8 גרם, נקח מקדם ביטחון של 12 )בכדי לכלול גם את ראש ואקום המותקן( ונבדוק את ביצועי הזרוע עבור משקל של 96 גרם.
מנוע הבסיס המותקן הוא מנוע מסוג D-15LX, המסוגל להפעיל מומנט מקסימלי של Nm/1.91kgcm,19.5 כפי שמתואר במדריך היצרן בעמוד 94 )2021 ,Robotics Elephant).

מומנט המקסימלי על מנוע הבסיס מתקבל כאשר מפרק 1J ו0-J מסובבים ב90- מעלות, ושאר המפרקים ב0- מעלות.
מכאן, הדג"ח על הזרוע:

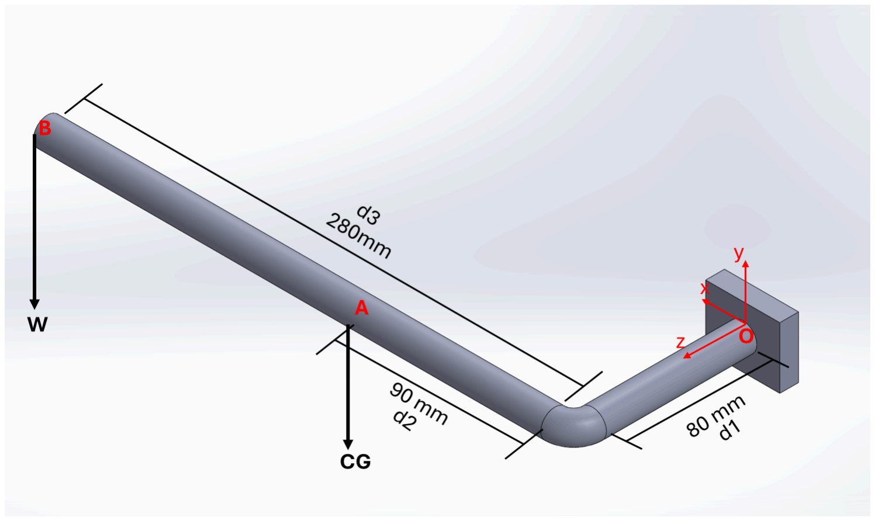
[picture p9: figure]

איור #11 - דג"ח על הזרוע

CG = 0. 515kg * 9. 81m/s

2 = 5. 05N

W = 0. 096kg * 9. 81m/s

2 = 0. 94N

הריאקציות בבסיס )נק' O):

∑ F

x = 0 ⇒ R

x = 0

∑ F

y =− W − CG + R
y

⇒ R

y = W + CG = 5. 99N

∑ F

z = 0 ⇒ R

z = 0

חישוב מומנטים בבסיס )נק' O):

Mx = 0. 479 Nm

M

y = 0 Nm

Mz = 0. 717Nm

המנוע מסוגל להפעיל מומנט בציר z של Nm,1.91 מהחישובים אנו רואים שהמומנט הפועל על המנוע בהתקנה אופקית הינו Nm,0.717 לכן המנוע יתפקד היטב במצב אופקי.

## .5 מתודולוגיות

לצורך פיתוח מנגנון חדש לזיהוי מיקום הפלת הדיסקית במשחק "ארבע בשורה", נבחנו שתי מתודולוגיות עיקריות: המשך עבודה עם מערכת הראייה הממוחשבת הקיימת, או פיתוח מערכת זיהוי אלקטרונית חדשה מבוססת חיישנים.

## .5.1 להישאר עם ראיה ממוחשבת

גישה זו מתבססת על המערכת המקורית שהייתה בשימוש במוצג, הכוללת מצלמה שמצלמת את הלוח בזמן אמת ואלגוריתם המזהה את מצב הדסקיות באמצעות עיבוד תמונה,לטיפול בכשלים הקיימים בפתרון הנוכחי הוצעו מספר פתרונות:
- הוספת מקורות תאורה חיצוניים לשיפור תנאי התאורה.

- הוספת סממן ייחודי על כל דיסקית )42 בסה"כ(, כדי להוריד את משתנה הצבע מהבעיה, ובכך לשלול את הבעיה של הביגוד של המשתמש.
- החלפת האלגוריתם הקיים )מבוסס רשת עצבית( באלגוריתם דטרמיניסטי.

היתרונות בשיטה זו:
- אפשר לעבוד עם המערכת הקיימת מבלי לשנות באופן מהותי את אופן עבודת המוצג.
- דרישה מועטה לשינויים מבניים.
- מאפשר ניטור מלא של מצב הלוח בעזרת רכיב אחד - המצלמה. החסרונות בשיטה זו:
- סממנים על הדסקיות עלולים להתבלות ולהוות 42 נקודות כשל.
- הוספת תאורה מלאכותית עלולה לפגוע בנראות ובחוויה של המשתמש.
- סביבת המוזיאון דינמית, ולכן לא נוכל לשלוט בכל המשתנים שראיה ממוחשבת דורשת כדי להגיע לביצועי אמינות גבוהים.
- מניסיון המוזיאון בראיה ממוחשבת, המוזיאון לא רוצה להישאר עם פתרון זה ורוצה לתכנן פתרון חלופי.

## .5.2 פתרון אלקטרוני מבוסס חיישנים

בגישה זו נבחנה תכנון של מערכת חדשה לזיהוי נפילת הדסקיות, המבוססת על חיישנים אופטיים פיזיים. נבחנו שלושה סוגי חיישנים:

.1 חיישנים אופטים על בסיס החזרה

במערכת זו לד אינפרא־אדום משדר אור לעבר הדיסקית, ופוטורזיסטור סמוך מודד את עוצמת ההחזר. כאשר דסקית נופלת, היא משנה את כמות האור החוזר, וכך ניתן לזהות את נוכחותה. בשיטה זו יהיה לנו חיישן אחד על כל אחת מ7- העמודות בלוח המשחק. היתרונות של חיישן זה:
- קומפקטי - הלד והחיישן נמצאים על אותו לוח.
- לא דורש התקנה מדוייקת.
- אמינות גבוהה.
- התקנה פשוטה בצד אחד בלבד של העמודה. החסרונות של חיישן זה:
- מושפע מצבע הדיסקית, ותוואי פני השטח שלה )בליעת האור, פיזור האור(.

כאשר נעשתה בדיקה עם הדיסקיות הקיימות במוצג התגלה שהן שקופות לאינפרא־אדום, ולכן לא מחזירות את אור החיישן בכלל. זוהי מגבלה קריטית שפוסלת את הפתרון הזה לחלוטין בתצורתו המקורית. )עובדה זו התגלתה בניסוי מהיר של צילום הדסקית באמצעות מצלמה טלפונית שמראה את האור האינפרא-אדום עובר דרכה, לאחר שבדיקות עם החיישן הראו שהוא לא מזהה את הדסקית(.

Time Of Flight - TOF | חיישני | .2

חיישני TOF הם חיישנים מבוססי לייזר המודדים את זמן ההחזר של האור לצורך חישוב מרחק מהאובייקט, בשיטה זו יהיה קיים רק חיישן אחד שיהיה מותקן באופן כזה שקרן הלייזר ממנו חותכת את כל 7 העמודות, ואז כאשר נופלת דיסקית היא תחתוך את קרן הלייזר וחישוב המרחק ייתן לנו את העמודה שבה אירע החיתוך.
יתרונות של חיישן זה:
- התקנה של חיישן יחיד
חסרונות של חיישן זה:
- דורש יישור מוקפד וקליברציה תכופה.
- רוחב קרן רחב מדי שאינו מאפשר להבחין בין עמודות סמוכות.

שיטה זו נפסלה בעקבות ניסיון קודם של המוזיאון שהעיד שלמקרה הספציפי של בעיה זו, תפקוד החיישן לא יביא תוצאות מספקות, והוא לא מתאים לפתרון שמחפשים.

.3 חיישנים אופטים על בסיס העברה

חיישנים אלה עובדים על עיקרון שיש לד המותקן אל מול חיישן אור )כמו פוטורזיסטור(, וכאשר עצם מסוים מגיע בין הלד לחיישן אור וחוסם אותו, המתח על חיישן האור משתנה ולפי קריאת המתח עליו אפשר לדעת אם קרתה חסימה. בשיטה זו יהיה לנו זוג לד-חיישן בכל אחת מ7- העמודות בלוח המשחק.
יתרונות שיטה זו:
- לא תלוי בתוואי שטח הדסקית, או בצבע שלה - עובד עם הדסקיות הקיימות.
- אמינות גבוהה.
חסרונות השיטה:
- דורש התקנה מדויקת של רכיבים משני צידי כל עמודה.

- מחייב שינוי במבנה הפיזי של המוצג.

## .5.3 המתודולוגיה שנבחרה

לאחר בחינה של כל האפשרויות של לגשת לבעיה, נבחר הפתרון של פתרון אלקטרוני מבוסס חיישנים, בשימוש עם חיישנים על בסיס העברה, הסיבה לבחירה זו היא: .1 המוזיאון לא רצה שימוש נוסף בראיה ממוחשבת )גם עם תיקונים(. .2 לפי ניסיון המוזיאון חיישני TOF לא מתאימים לפרויקט זה. .3 חיישנים על בסיס החזרה הקיימים במוזיאון נוסו, אך התגלה שהם לא עובדים עם הדיסקיות הקיימות, ושהן שקופות לאור אינפרא-אדום, ולכן אפשרות זו ירדה.

ולכן נשארנו עם הפתרון של חיישנים על בסיס העברה.

## .6 יישום ופיתוח הפתרון

כפי שצויין בפרק 5 - "מתודולוגיות" הפתרון שהוחלט לעבוד איתו הוא חיישנים אופטים על בסיס העברה, בכדי לממש פתרון זה צריך לקבוע מספר פרמטרים באמצעות סדרת ניסויים: .1 ניסוי לקביעת חיישן מתאים. .2 ניסוי לקביעת לד מתאים מבחינת עוצמה וצבע. .3 תכנון תקשורת בין הזרוע לבין החיישנים החדשים, באמצעות מיקרו בקרים. .4 תכנון מכני להתקנת החיישנים בכל אחת מהעמודות. .5 כתיבת תוכנה לאיסוף ועיבוד נתוני החיישנים בזמן אמת.

בכדי להתחיל עם הניסוי לקביעת החיישן המתאים קודם צריך לדעת מה זמן התגובה הרצוי שלנו, לשם כך נדרש לחשב כמה זמן דיסקית נופלת תהיה מול החיישן.

## .6.1 חישוב זמן חסימת החיישן על ידי דיסקית נופלת

הזמן שהחיישן חסום הוא הזמן הלוקח לדיסקית לעבור מרחק השווה לקוטר אחד שלה.

בכדי לחשב זאת עלינו לעשות דג"ח על הדיסקית ולהשתמש בנוסחאות התנועה תחת תאוצה קבועה.

איור #12 - דג"ח של דיסקית בנפילה חופשית

v = v | )6.1.1( 0 + gt
v | )6.1.2(
0

t +

1
2

gt

2
∆x =

ב6.1.2 קיבלנו ביטוי להעתק אותה עוברת הדיסקית בזמן t, ובמהירות התחלתית 0v.

מכיוון שבשלב זה של הפרויקט לא תוכנן עדיין מיקום ההתקנה המדויק של החיישנים, אי אפשר לדעת באיזה מהירות תחתית הדיסקית תתחיל לעבור מול החיישן - אנחנו לא יודעים כמה זמן הדיסקית כבר הייתה בנפילה מהשחרור שלה עד הגעתה לחיישן. לכן נגדיר פרמטר חדש d שהוא המרחק מנקודת השחרור בהחסרת רדיוס אחד של הדיסקית עד לחיישן, כמתואר באיור :#13

איור -#13 הגדרת פרמטר d של הדיסקית הנופלת על ידי בידוד t ממשוואה 6.1.1 והצבתו ב6.1.2 אפשר לקבל ביטוי למהירות הדיסקית בהגיעת הגבול התחתון שלה לחיישן:

v | )6.1.3(
0 = | v'
| 0
| 2
| + 2gd

0'v זוהי המהירות שבה הדסקית שוחררה על ידי המשתמש, אמנם בגלל גיאומטרית החריץ למשתמש אין יכולת להפעיל הרבה כוח על הדיסקית, נקח ערך מסוים למשתנה זה כדי לדמות מקרה קיצוני בו המשתמש מצליח להפעיל כוח על הדיסקית ולשחרר אותה עם מהירות התחלתית גבוהה.

כאשר נפתור את משוואה 6.1.2 בשילוב עם 6.1.3 עבור t נקבל את הנוסחה הבאה:

)6.1.4( t =

− v
0

2+2gd+ v
0

2+2g(d+△x)

g
כאשר:
- 0v - המהירות אותה שחרר המשתמש את הדיסקית. ]s/m]
- d - המרחק בין הקצה התחתון של הדיסקית למרכז החיישן כמתואר באיור .#10 ]m]
- Δx - המרחק שאנחנו מודדים את זמן הנפילה שלו )במקרה שלנו הקוטר של הדיסקית(. ]m]
- t - הזמן ליפול Δx לאחר שכבר נפלנו מרחק של d. אם ניצור גרף של משוואה 6.1.4 עבור מהירויות התחלתיות שונות נקבל את התמונה הבא:

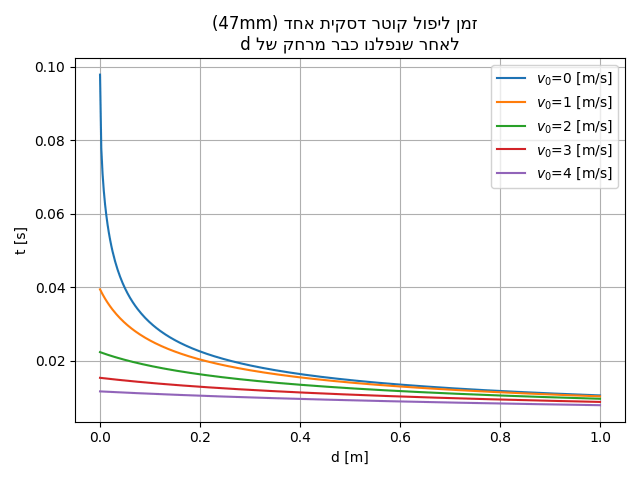
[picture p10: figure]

איור #14 - גרף של זמן נפילת דיסקית עם מהירויות התחלתיות שונות

בגרף אנו רואים את הזמן הלוקח לדיסקית ליפול מרחק השווה לקוטר אחד שלה בציר Y, והמרחק d בציר X, בנוסף אנחנו רואים חמש עקומות שונות כל אחד עבור ערך מהירות התחלתית שונה. לדוגמה, אם ניקח מקרה קיצון של מרחק הפלה של cm10 מהחיישן והמהירות הפלה התחלתית של s/m4 נקבל זמן חסימת חיישן של ms,11.79 ערך זה מייצג את הגבול העליון לזמן התגובה הנדרש מהמערכת.

בהשוואה לכך, זמני התגובה של בקרי Arduino ו־32ESP נמצאים בסדר גודל של מיקרו־שניות )µs), כלומר קצרים בלפחות שני סדרי גודל מזמן החסימה של הדיסקית. לכן, שני הבקרים נחשבים מתאימים לעיבוד אות החיישן בזמן אמת.

מכאן נובעת הדרישה שלחיישן האופטי שייבחר למערכת חייב להיות זמן תגובה קצר מ ms,11.79 כדי להבטיח זיהוי מלא של הדיסקית בעת נפילתה.

## .6.2 בחירת הלד המתאים

מכיוון שהחיישן מבוסס על מקור אור, וסוג מקור האור התברר כמשתנה קריטי לתפקוד התקין של המערכת )ראינו לדוגמא שהדיסקיות היו שקופות למקור אור אינפרא-אדום(, צריך לקבוע איזה צבע של לד מתאים למערכת באמצעות ביצוע ניסוי. כדי לקבוע את צבע הלד המתאים ביותר צריך להגדיר את הפרמטר שנרצה למקסם שייתן לנו את ההגדרה ל"לד המתאים ביותר". הפרמטר שאנחנו רוצים למקסם הוא אחוז החסימה של האור כאשר הדיסקית עומדת בין מקור האור לחיישן, לשם בדיקה זו צריך להגדיר את מערכת הניסוי:

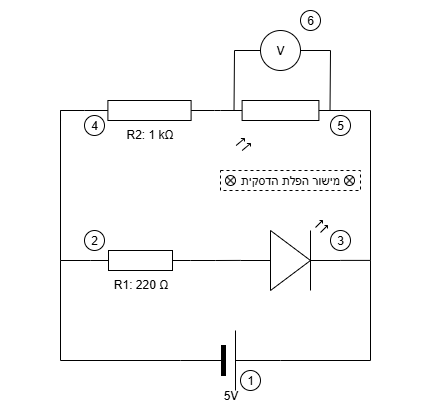
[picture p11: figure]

איור #15 - מערכת הניסוי לבחירת צבע לד

באיור #15 אנחנו רואים את המעגל החשמלי של מערכת הניסוי, תיאור המרכיבים:

.1 מקור המתח של המעגל - V.5 .2 נגד קבוע בעל ערך של 220 אוהם. .3 לד.
.4 נגד קבוע בעל ערך של 1 קילו אוהם. .5 הפוטורזיסטור.
.6 נקודת קריאת המתח.

במעגל ישנם שני ענפים:
הענף התחתון מפעיל את הלד, כאשר קיים נגד אחד בטור עם הלד בכדי להגביל את הזרם הנופל על הלד לזרם בטוח )מתחת ל-mA30 )- נבחר זרם יעד של mA,20 ונחשב את ההתנגדות הנדרשת על פי נוסחה 2.3.1 - חוק אוהם:

V = RI ⇒ R =

V
I =

5
0.02 = 250 Ω
הנגד הזמין הקרוב ביותר שנמצא היה Ω,220 והזרם עם נגד זה הוא mA,22.7 שהוא בתחום הבטוח ולכן התקבל למערכת הניסוי.

בענף העליון קיים מחלק מתח עם נגד אחד קבוע בעל ערך של kΩ1( בכדי להוריד את רגישות המערכת(, ופוטורזיסטור, המתח נמדד על הפוטורזיסטור כדי לאמוד את עוצמת האור הפוגעת בו.

יש לציין כי בניסוי זה אנחנו מעוניינים רק בהפרש בין מצב חסום ולא חסום, ולכן עוצמת האור האבסולוטית של הלד אינה חשובה.

לבדיקת מצב החסימה, מציבים את הדיסקית בין הלד לחיישן )מישור הפלת הדיסקית(. לביצוע הניסוי נלקחו 8 מדידות, שתי מדידות עבור כל לד )אחת עם דיסקית אדומה ואחת עם דיסקית צהובה( עבור ארבע חזרות עם צבעי לד שונים - אדום, ירוק, צהוב וכחול.

בניסוי נמדד המתח על הפוטורזיסטור בשני מצבים:
- ללא חסימה - החלל בין הלד לפוטורזיסטור היה ללא דיסקית.
- עם חסימה - דיסקית מוצבת בין הלד לחיישן. מתוך שני מדידות אלה חושב אחוז החסימה:

Fraction [%] =

V

blocked−V
unblocked
V
in
- 100%

בכמה אחוז גדל המתח על החיישן )לעומת מצב לא חסום( מתוך מתח המקור.

התוצאות מסוכמות בטבלה #2 ובגרף המצורף )איור #16(

אחוז הבדל בדיסקית אדומה ]%[ | אחוז הבדל בדיסקית צהובה ]%[ | מתח עם דיסקית צהובה ]V[ | מתח עם דיסקית אדומה ]V[ | מתח ללא חסימה ]V[ | צבע לד
| | | | | אדום 0.17 1.6 1.8 32.6 28.6
| | | | | ירוק 0.22 4.74 4 75.6 90.4
| | | | | צהוב 0.17 4.63 2 36.6 89.2
| | | | | כחול 0.12 4.76 4.61 89.8 92.8

טבלה #2 - תוצאות ניסוי בחירת צבע לד

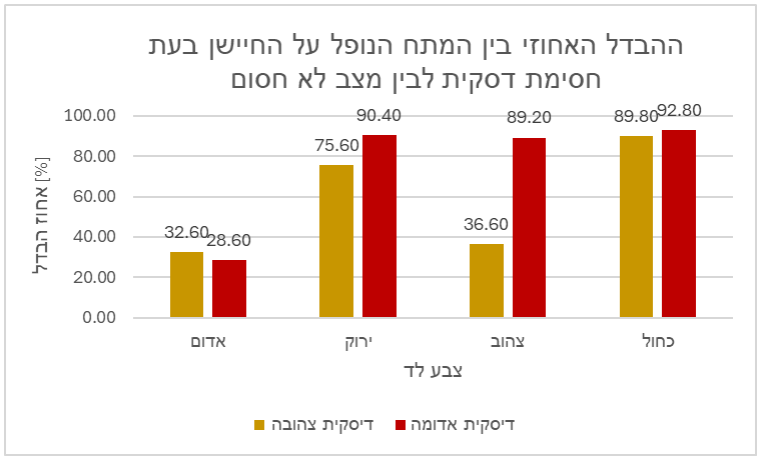
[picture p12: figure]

איור #16 - גרף תוצאות ניסוי בחירת צבע לד

מתוצאות הניסוי אנחנו רואים שהלד שהכי מתאים לקריטריון שהגדרנו הוא הלד הכחול מכיוון שאיתו שני הדסקיות חוסמות את האור באופן הטוב ביותר.

לכן צבע הלד שנבחר למערכת הוא כחול.

## .6.3 בחירת הנגד המתאים למחלק המתח

בכדי לקרוא את המתח הנופל על הפוטורזיסטור, הוא מחובר בטור לנגד קבוע ליצירת מחלק מתח. התנגדות הפוטורזיסטור משתנה בהתאם לעוצמת התאורה, וערך הנגד הקבוע קובע את רגישות המערכת לשינויים אלו.

במיקרו בקרים שבהם נשתמש )Arduino ו32ESP), הפינים הדיגיטליים מזהים רמה לוגית גבוהה )HIGH )כאשר המתח על הפין גבוה ממתח סף מסוים, V3 עבור Arduino ו-V 2.475 עבור 32ESP. לכן כאשר המתח על הפוטורזיסטור עולה מעל ערך זה, המערכת תזהה אותו כחסום. אבל בכדי להבטיח פעולה אמינה גם בתנאי סביבה משתנים, הוגדר מקדם ביטחון כך שזיהוי של מצב "חסום" יתבצע בפועל רק כאשר המתח עולה למעל V .3.5

כדי לראות את השפעת ערך הנגד הקבוע על רגישות המערכת, נבנה גרף לפי נוסחת מחלק המתח )נוסחה 2.6.1( עבור ערכי נגד קבוע שונים, כאשר מתח הכניסה הוא V .5 בנוסף, הוסף קו אופקי מקווקו המייצג את סף הזיהוי בפועל למצב "חסום" - V.3.5

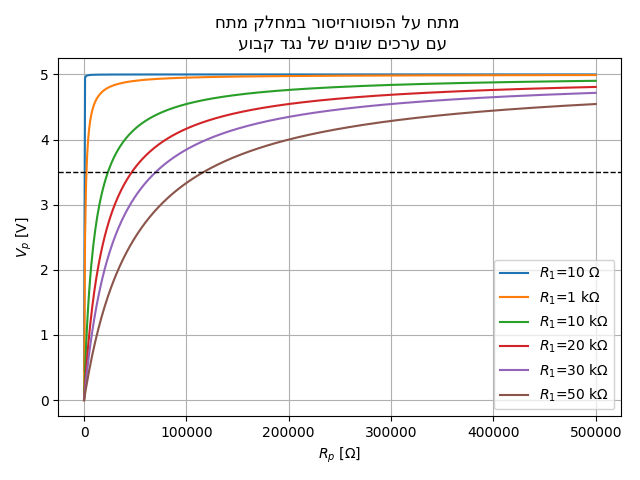
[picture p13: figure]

איור #17 - השפעת נגד קבוע במחלק מתח

בגרף אפשר לראות שעקומת המתח על הפוטורזיסטור מושפעת משמעותית מערך הנגד הקבוע. אם נסתכל על העקומה שמתאימה לערך נמוך במיוחד של הנגד הקבוע )Ω10 )תחום התנגדות של הפוטורזיסטור שבו המתח עובר מעל סף הזיהוי הוא צר מאוד - העקומה כמעט אנכית. במצב כזה כל שינוי מזערי בתנאי התאורה יכול לגרור לעליית המתח מעל הסף ולהוביל לקריאה שגוייה. לעומת זאת אם נסתכל על העקומה שבה ערך הנגד הקבוע הינו kΩ,50 אפשר לראות שתחום ההתנגדות שבו המתח מתחת לסף הזיהוי רחב )כkΩ110), מצב זה מצביע על רגישות נמוכה להפרעות קטנות, הודות למרווח ביטחון גדול יותר.

עם זאת, ערכים גבוהים מדי של הנגד הקבוע עלולים להוביל לחוסר רגישות, כך שגם במצב של חסימה המתח יישאר מתחת לסף הזיהוי. לכן נדרש למצוא את ערך הנגד הקבוע המאזן בין רגישות מספקת לבין חסינות לרעשים והפרעות.

בכדי לקבוע את ערך הנגד, נעשה ניסוי שבו נבנה מעגל חשמלי של מחלק מתח שבו הנגד הקבוע היה פוטנציומטר, ונלקחו מדידות של חסימת הפוטורזיסטור באמצעות כל צבע דיסקית, וחושב אחוז ההבדל בין מצב חסום ללא חסום כאשר אחוז גבוה יותר מראה מרווח ביטחון יותר טוב.

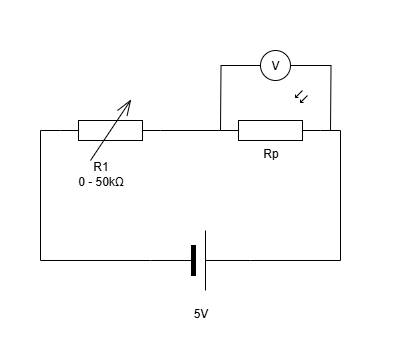
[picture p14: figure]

איור #18 - מעגל הניסוי לקביעת ערך נגד קבוע

טבלה #3 מציגה את המתח הנמדד על הפוטורזיסטור בשני מצבים - לא חסום וחסום )עם דיסקית אדומה או צהובה(, עבור ערכים שונים של הנגד הקבוע. בנוסף מוצג מרווח הבטיחות הממוצע מנקודת הסף שנקבעה )3.5 V), באחוזים, שחושב באופן הבא:

[%] =

V

block−avg−3.5

3.5

- 100% ; V

block−avg =

V

blocked−yellow+V
blocked−red
2

| מתח הפוטורזיסטור
מרווח ממוצע מנקודת הסף ]%[ | חסום - דיסקית צהובה [V] | חסום - דיסקית אדומה [V] | לא חסום ]V[ | ערך נגד ]kΩ[
62.29- | 5 | 5 | 3.68 | 1
20.43 | 4.88 | 4.95 | 0.7 | 13.6
18.71 | 4.81 | 4.9 | 0.7 | 22
17.14 | 4.7 | 4.82 | 0.66 | 40
15.57 | 4.61 | 4.78 | 0.65 | 50

טבלה #3 - תוצאות ניסוי בחירת נגד קבוע מהתוצאות ניתן לראות כי ערך התנגדות של kΩ 13.6 סיפק את מרווח הבטיחות הגדול ביותר של כ20%- מעל סף הזיהוי. עם זאת, גם ערכים בטווח שבין kΩ 13.6 לבין kΩ 50 נתנו מרווח בטיחות דומה, ולכן כולם נחשבים מתאימים לשימוש. הערך שנבחר בפועל לנגד הקבוע הוא kΩ ,20 מאחר שזהו ערך סטנדרטי שנמצא במלאי, והוא מספק מרווח בטיחות מספק יחד עם זמינות גבוהה.

## .6.4 שילוב עם המיקרו בקר

לאחר בחירת החיישן, הלד והנגד הקבוע, הושלמה מערכת זיהוי הדיסקית הבודדת. כדי לאפשר קליטה בכל שבע העמודות, המערכת שוכפלה פי ,7 מה שיוצר צורך בקריאת שבעה קווים נפרדים.
מכיוון שבקר הזרוע אינו כולל מספיק פינים פנויים, נבחר שימוש באוגר זיזה מסוג 165HC,74 המאפשר קריאת מספר קלטים מקבילים דרך קו טורי אחד בלבד. השימוש בו הפחית את דרישת הפינים לשלושה: קו נתונים, קו שעון וקו טעינה.

החיישנים חוברו לאוגר הזיזה )איור #19(, והוא חובר ישירות לבקר הזרוע. לצורך בדיקה ראשונית, חובר חיישן אחד בלבד, ושאר הכניסות דומו באמצעות מתגים.

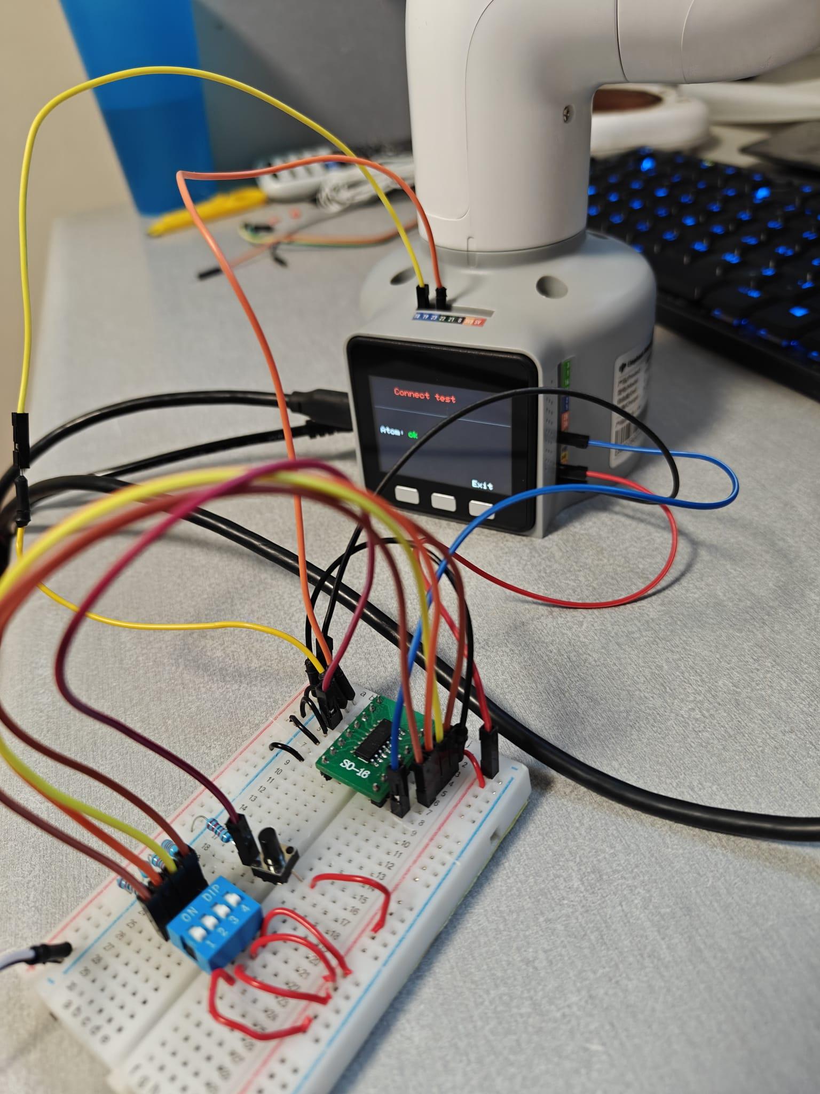
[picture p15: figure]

איור #19 - אוגר זיזה מחובר לבקר הזרוע

לאחר ההתקנה, המערכת לא קלטה את נפילת הדסקיות למרות שבניסויים קודמים החיישנים הגיבו בהצלחה.
בבדיקת התופעה התברר שהבעיה נובעת מהבקר עצמו, אף שמבחינה תיאורטית ה32ESP מהיר מאוד )בקנה מידה של מיקרו שניות(, הרצת הקושחה בשפת פייתון גרמה לכך שקצב קריאת הנתונים בפועל היה איטי בהרבה, עד שלא ניתן היה לזהות אירוע קצר של כ11 מילישניות. המסקנה הייתה שיש להוסיף בקר חיצוני שיטפל בקריאת החיישנים. הבקר שנבחר הוא ארדואינו, שיקרא את מצב החיישנים בזמן אמת ויעביר את המידע אל הבקר המפעיל את הזרוע.
מכאן עלתה השאלה, כיצד יעביר הארדואינו את המידע על מצב החיישנים לבקר.

בנוסף, הוחלט שאם כבר מחברים בקר חיצוני, הוא יהיה אחראי גם על הפעלת הסולנואידים, המשאבה וכפתור ההתחלה. כך יופחת העומס מבקר הזרוע, והוא יתמקד אך ורק בשליטה על תנועת הזרוע.

## .6.5 תכנון פרוטוקול התקשורת

בקר הזרוע נשלט באמצעות פקודות המתקבלות מתוכנה שרצה על מחשב בשפת Python, בעזרת ספריית pymycobot, דרך חיבור Serial( חיבור USB סטנדרטי(. כדי לאפשר שליטה בזרוע בהתאם למצב החיישנים, התוכנה נדרשת לקבל את נתוני החיישנים מבקר הארדואינו ולעבד אותם בזמן אמת. גם התקשורת בין התוכנה לארדואינו מתבצעת באמצעות .Serial

במבנה המערכת, המחשב שולח נתונים לבקר הזרוע בלבד, בעוד שבקשר עם הארדואינו מתבצע תקשורת דו כיוונית: המחשב שולח פקודות )כגון הפעלת המשאבה, הפעלת הסולנואידים( ומקבל מהארדואינו מידע חזרה )כגון מספר העמודה שבה זוהתה נפילה(.

סכמת התקשורת בין הרכיבים מתוארת באיור .#20

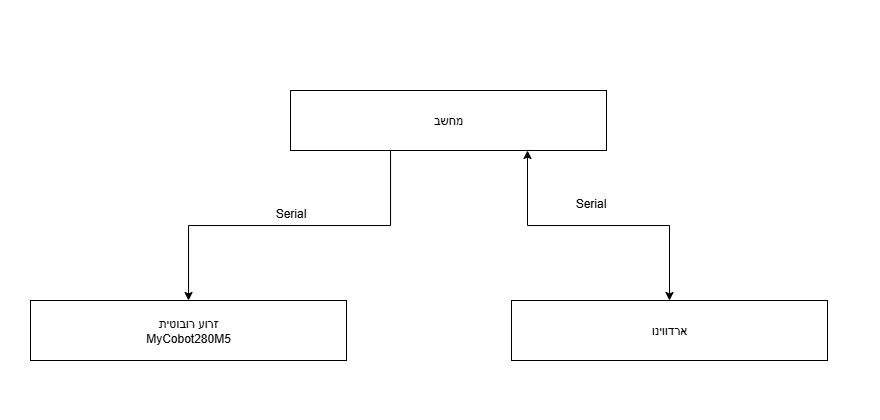
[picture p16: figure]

איור #20 - דיאגרמת התקשורת בין המחשב לבקרים השונים

הקוד על גבי הארדואינו נכתב בשפת C, שבה אין מנגנוני תקשורת מובנים ונוחים כמו בפייתון. כל שליחת וקבלת נתונים מחייבת טיפול ידני בביטים ובבתים, ניהול באפרים, בדיקת שגיאות ותזמון הקריאות. בפייתון, לעומת זאת, ניתן להשתמש בספריות קיימות שמסתירות את המורכבות הזו ומאפשרות לכתוב קוד תקשורת בכמה שורות פשוטות.

כדי לפשט את היישום בצד הארדואינו, הוחלט שכל הנתונים יועברו באמצעות בייט יחיד. פרוטוקול התקשורת מקודד את המידע בתוך הבייט באמצעות ביטים ייעודיים, כך שכל ביט מייצג פרמטר או מצב מסוים במערכת, וביחד הם יוצרים את חבילת המידע המלאה.

מבנה הבייט בפרוטוקול שתוכנן:

10101010
הביט האדום הינו ביט ההכרה - מסמן שההודעה נשלחה מהארדואינו בתור אישור על קבלת וביצוע הפקודה שהתקבלה.

הביטים הכחולים - מייצגים את מספר הפקודה )בבינארית(. הביטים הירוקים - מייצגים את פרמטר הפקודה )בבינארית(.

בטבלה הבאה ניתן לראות את כל האפשרויות למבנה הבייט:

| | מסכת הפקודה ערך מספרי תיאור פרמטרים אפשריים
0 - לכבות את המשאבה 1 - להדליק את המשאבה | המשאבה | 001 1 פקודה לשליטת מצב
החסימה )0000-0111( | | 010 2 נקלטה נפילת דיסקית 7...0 - העמודה בה נקלטה
| | 011 3 כפתור ההתחלה נלחץ 1 - הכפתור נלחץ
להפעיל את הסולנואיד )0000-0111( | | 100 4 הפעלת סולנואיד 7...0 - העמודה בה נדרש

טבלה #4 - מבנה בייט התקשורת

לצורך המחשת אופן עבודת הפרוטוקול ניקח דוגמה לתקשורת בין המחשב לארדואינו:

נניח שהתוכנה במחשב רוצה להפעיל את הסולנואיד של עמודה מספר ,5 הבייט שישלח לארדואינו יהיה:
01000101
0 – ביט ההכרה כבוי, רק הארדואינו משתמש בו. 100 – מספר הפקודה )4 בבינארית, הפעלת סולנואידים(.

0101 – ערך הפרמטר )5 בבינארית, מספר העמודה(.

כאשר הארדואינו מקבל את הבייט ומבצע בהצלחה את הפקודה, הוא שולח חזרה את אותו הבייט, אך עם ביט ההכרה מופעל:
11000101
בצורה זו, המחשב יכול לוודא שהפקודה התקבלה, פוענחה ובוצעה כראוי.

הקוד לתקשורת מופיע בנספחים.

## .6.6 עיצוב התוכנה

התוכנה להרצת המוצג עוצבה באופן מודולרי באופן כזה שיהיה אפשר להחליף כל חלק במוצג בלי לשנות את התוכנה באופן משמעותי.

התוכנה חולקה לשלושה מודולים: .1 מודול לדיבור עם הארדואינו בשימוש עם הפרוטוקול שעוצב בפרק ,6.5 את הדיבור מממשת מחלקה בשם communicator.
.2 מחלקה המממשת ממשק לדיבור עם הזרוע הרובוטית שעושה אבסטרקציה לספרייה של הזרוע, בכדי שבעתיד יהיה אפשר להחליף את הזרוע בלי לשנות את כל הקוד, אלא רק את מימוש הממשק.
.3 המודול המרכזי שמריץ את הלוגיקה של המשחק ומנהל את שני המודולים האחרים.

אפשר לראות את מבנה התוכנה הכללי באיור #21

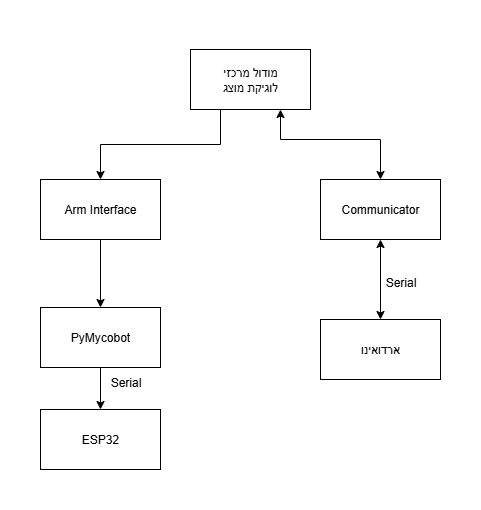
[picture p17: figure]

איור #21 - דיאגרמה של המודולים של התוכנה

אופן העבודה המרכזי של המודול המרכזי שאחראי על לוגיקת המוצג מתואר באיור #22 ו #23

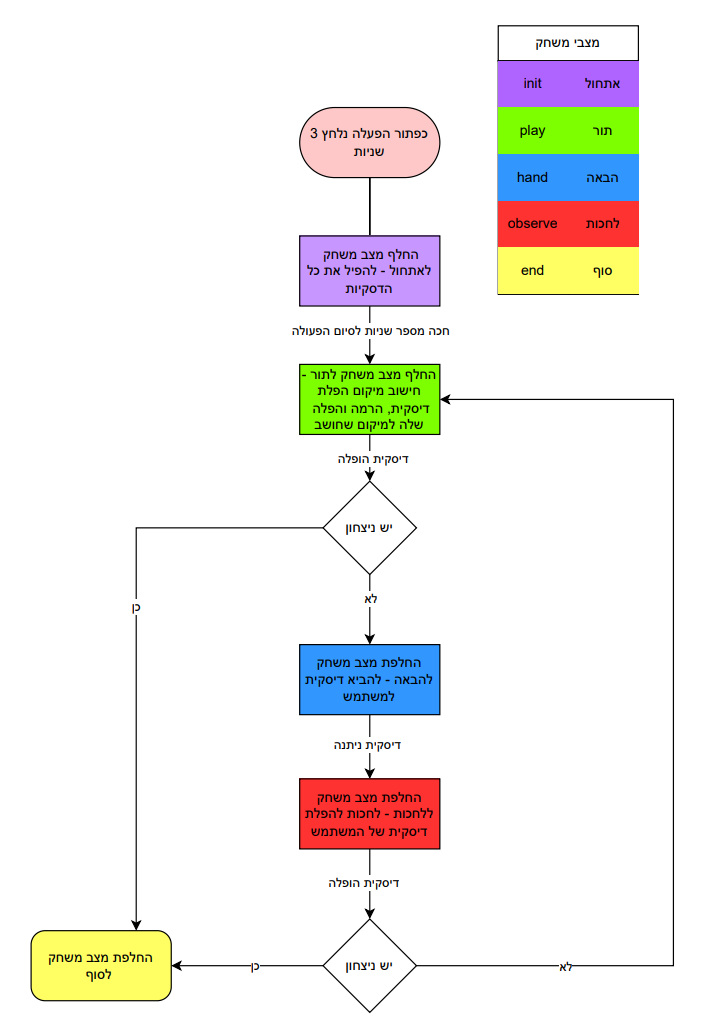
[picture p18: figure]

איור #22 - תרשים הזרימה של לוגיקת המוצג

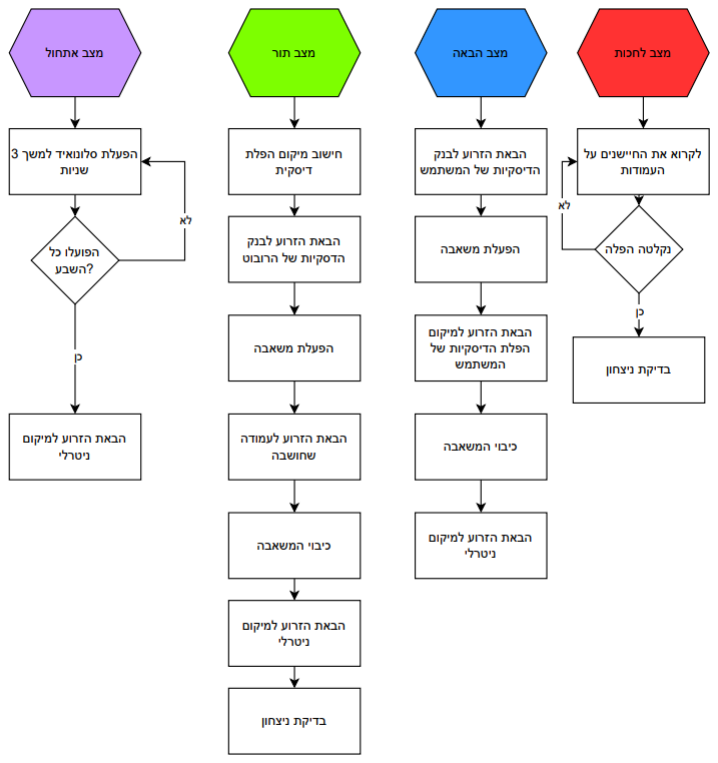
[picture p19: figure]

איור #23 - תיאור מפורט של שלבי התוכנה

## .6.7 מידול הפתרון

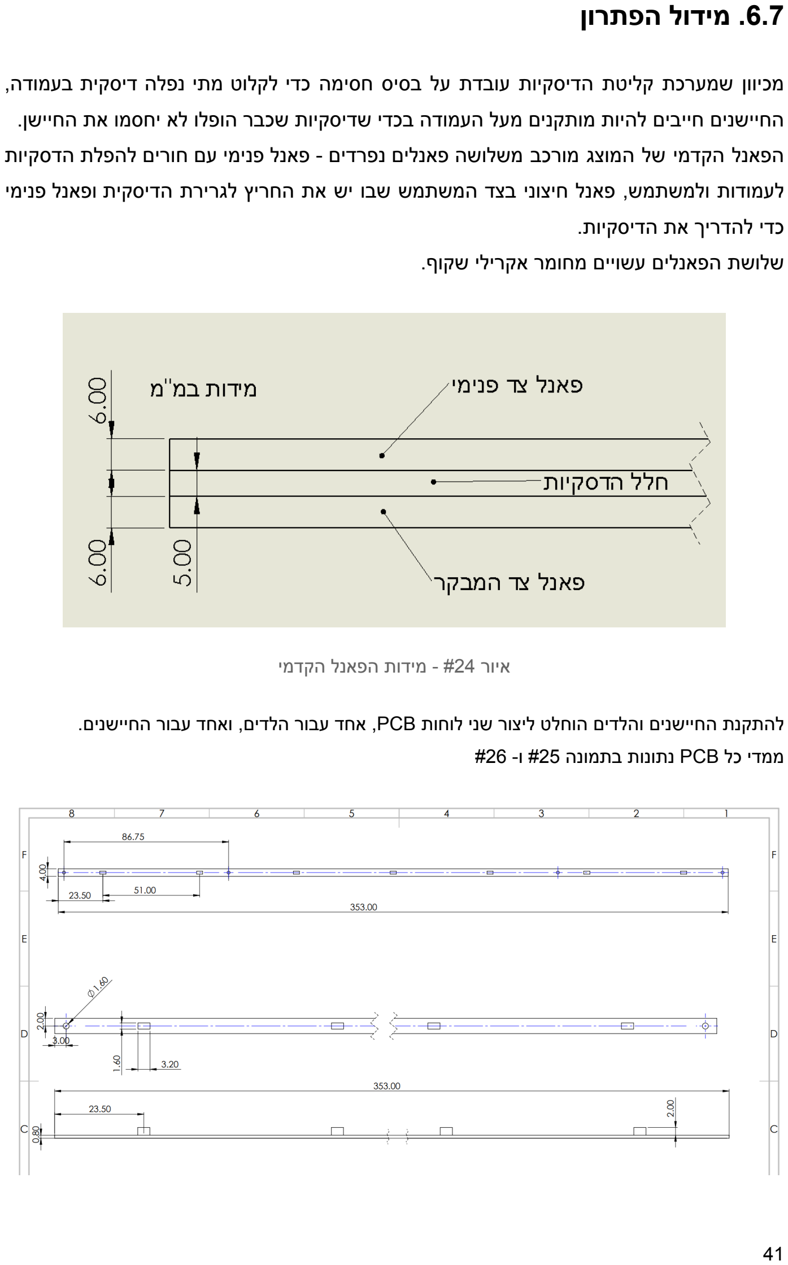
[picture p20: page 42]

מכיוון שמערכת קליטת הדיסקיות עובדת על בסיס חסימה כדי לקלוט מתי נפלה דיסקית בעמודה, החיישנים חייבים להיות מותקנים מעל העמודה בכדי שדיסקיות שכבר הופלו לא יחסמו את החיישן. הפאנל הקדמי של המוצג מורכב משלושה פאנלים נפרדים - פאנל פנימי עם חורים להפלת הדסקיות לעמודות ולמשתמש, פאנל חיצוני בצד המשתמש שבו יש את החריץ לגרירת הדיסקית ופאנל פנימי כדי להדריך את הדיסקיות.
שלושת הפאנלים עשויים מחומר אקרילי שקוף.

איור #24 - מידות הפאנל הקדמי

להתקנת החיישנים והלדים הוחלט ליצור שני לוחות PCB, אחד עבור הלדים, ואחד עבור החיישנים. ממדי כל PCB נתונות בתמונה #25 ו- #26

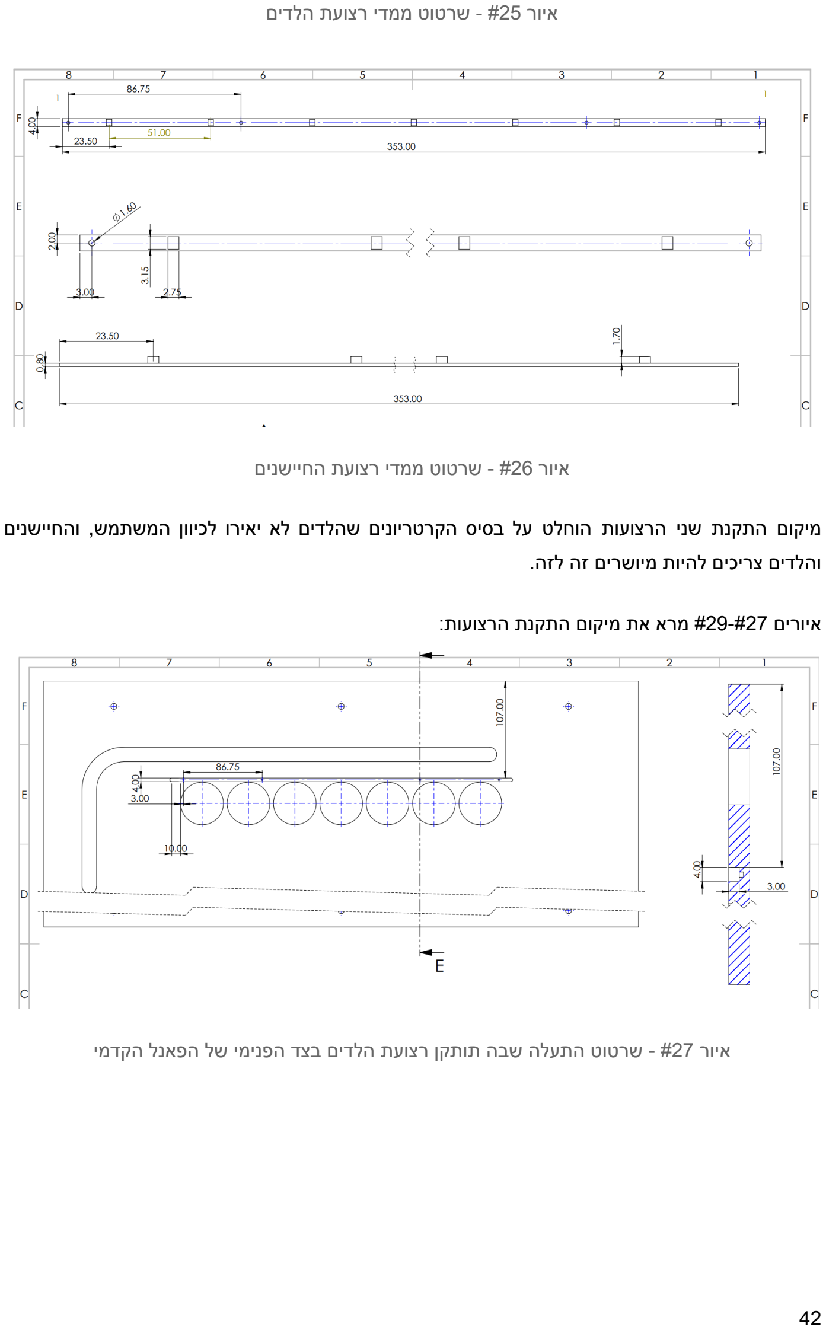
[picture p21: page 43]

איור #25 - שרטוט ממדי רצועת הלדים

איור #26 - שרטוט ממדי רצועת החיישנים

מיקום התקנת שני הרצועות הוחלט על בסיס הקרטריונים שהלדים לא יאירו לכיוון המשתמש, והחיישנים והלדים צריכים להיות מיושרים זה לזה.

איורים #29-#27 מרא את מיקום התקנת הרצועות:

איור #27 - שרטוט התעלה שבה תותקן רצועת הלדים בצד הפנימי של הפאנל הקדמי

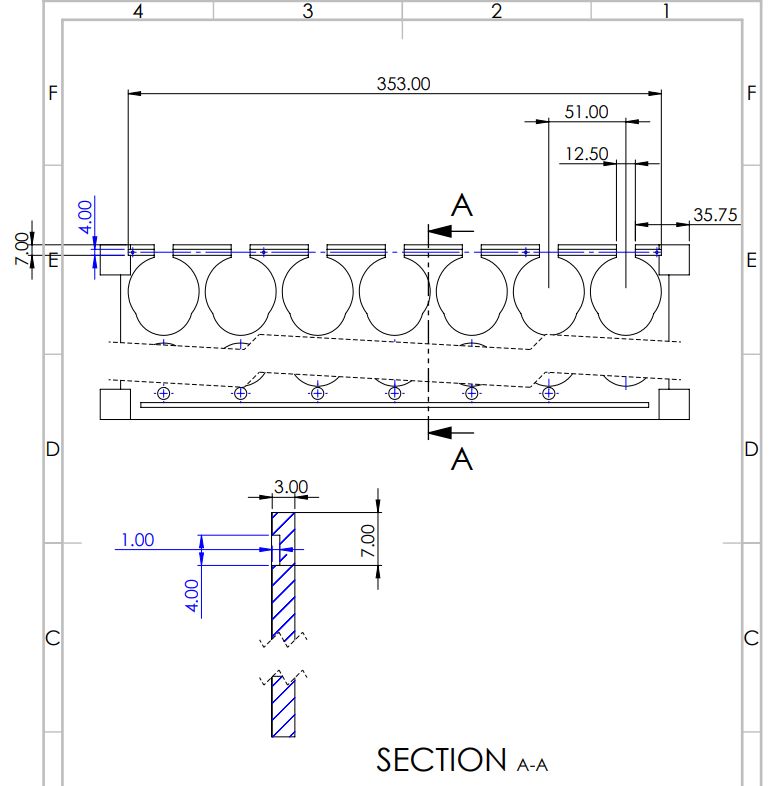
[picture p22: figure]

איור #28 - שרטוט התעלה שבה תותקן רצועת רצועת החיישנים

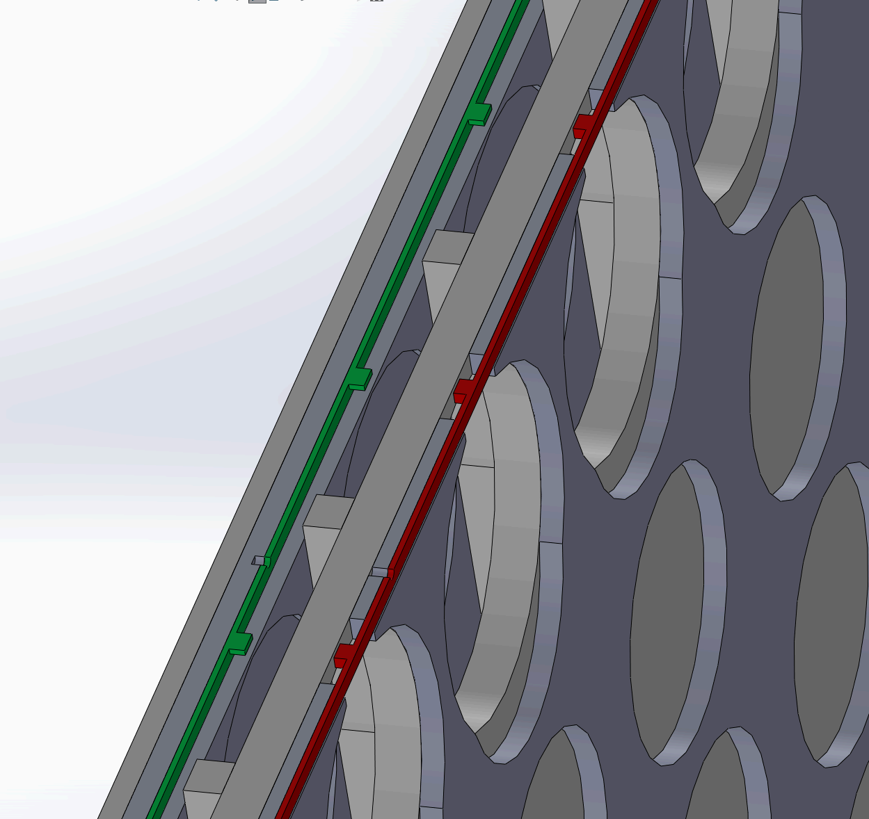
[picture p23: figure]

איור #29 - התקנת הרצועות החיישנים במוצג הסופי

)במהלך הפיתוח מערכת קליטת הדסקיות נבדקה גם עם הפאנלים האקרילים בין הלד לחיישן(

## .7 תוצאות

המערכת זיהתה, במהלך עשרות ניסויי הפלה, את חסימת הפוטורזיסטור והמיקום המדויק שבו אירעה החסימה באמינות של 100% , בהתקנה הסופית בין שני הפאנלים האקריליים, וגם כאשר חוברו מספר חיישנים לבקר בו-זמנית.

התוכנה והבקרים פעלו כמצופה ללא מצבי קצה חריגים, ושילוב הסולנואידים לניקוי העמודות וכן כפתור ההפעלה השתלבו בבקר החדש ללא תקלות.

למרבה הצער, הרצועות הסופיות שהוזמנו לא הספיקו להגיע ולהיבנות לפני תאריך הגשת דוח זה, ולכן הביצוע הסופי במוצג עצמו לא נבדק עקב גורמים חיצוניים שלא היה עליהם שליטה.

## .8 תכנון מול ביצוע

הפרויקט התקדם ברובו לפי התכנון המקורי המתואר בתרשים הגאנט )נספח 10.1(. גוש המחקר וההיכרות וכן גוש התכנון הושלמו במלואם ועל פי הלו"ז. העיכוב באספקת הרצועות הסופיות מנע את ביצוע גוש ההתקנה, וגרר שיבוש בלוחות הזמנים של הגושים העוקבים.

כל יעדי הפרויקט הושגו, למעט יעד :6 יישום אלגוריתם דטרמיניסטי "בלתי מנוצח" לתכנון מהלכי הזרוע. בשל קשיים וסיבוכיות שלא נצפו מראש הוחלט להחליפו באלגוריתם למידת מכונה מאתגר מאוד, אך כזה שאינו מבטיח ניצחון ב 100% מהמשחקים, ולכן עדיין ייתכן שהמבקר יגבור על הזרוע.

רכיבי התוכנה והתקשורת פעלו בדיוק כמתוכנן, והאינטגרציה בין המערכת החדשה לישנה הושלמה בהצלחה, ואי אפשר להבדיל בין המצב הישן לחדש.

## .9 ביבליוגרפיה

Allis, V. (1988, October). A Knowledge-based Approach of Connect-Four [The Game is

.]Solved: White Wins

ARDUINO. (2024, May 15). HIGH | LOW. Arduino Documentation.

/https://docs.arduino.cc/language-reference/en/variables/constants/highLow

Elephant Robotics. (n.d.). Docs, file downloads [3D model, Mycobot280 M5]. Elephant

Robotics.

https://docs.elephantrobotics.com/docs/myarm-pi-300-en/4-BasicApplication/4.5-files

_download.html

Elephant Robotics. (2021). User Manual [MyCobot]. elephantrobotics.

https://docs.elephantrobotics.com/docs/pdf/myCobot-en.pdf

Espressif Systems. (2016). ESP32 Datasheet [Page 33].

https://cdn.sparkfun.com/datasheets/IoT/esp32_datasheet_en.pdf

Texas Instruments. (2015). SNx4HC165 8-Bit Parallel-Load Shift Registers [Page 3].

https://www.ti.com/lit/ds/symlink/sn74hc165.pdf

Texas Instruments. (2021). SNx4HC595 8-Bit Shift Registers With 3-State Output Registers

[Page 3]. Texas Instruments. https://www.ti.com/lit/ds/symlink/sn74hc595.pdf

## .10 נספחים

## .10.1 תרשים GANTT

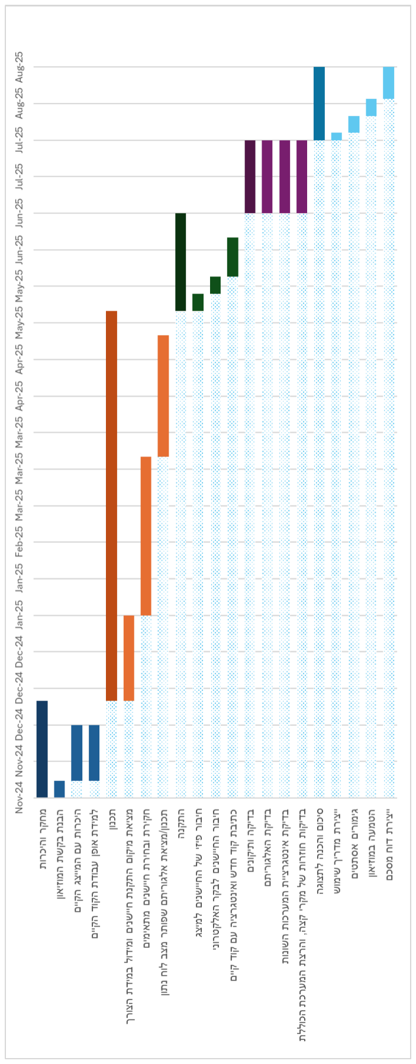
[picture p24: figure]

## .10.2 תרשים WBS

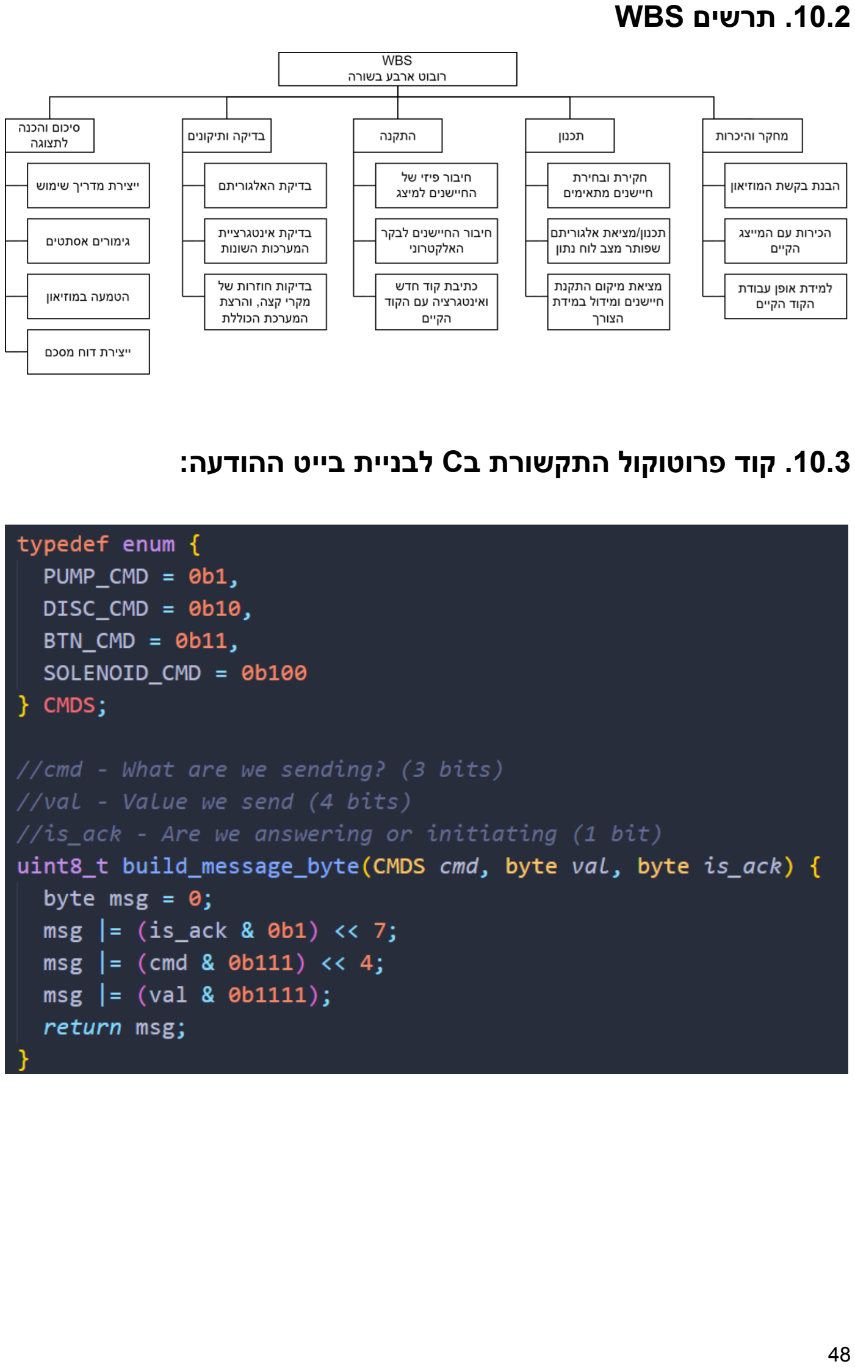
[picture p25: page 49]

## .10.3 קוד פרוטוקול התקשורת בC לבניית בייט ההודעה:

## .10.4 הקוד בפייתון ליצירת ופיענוח הודעה:

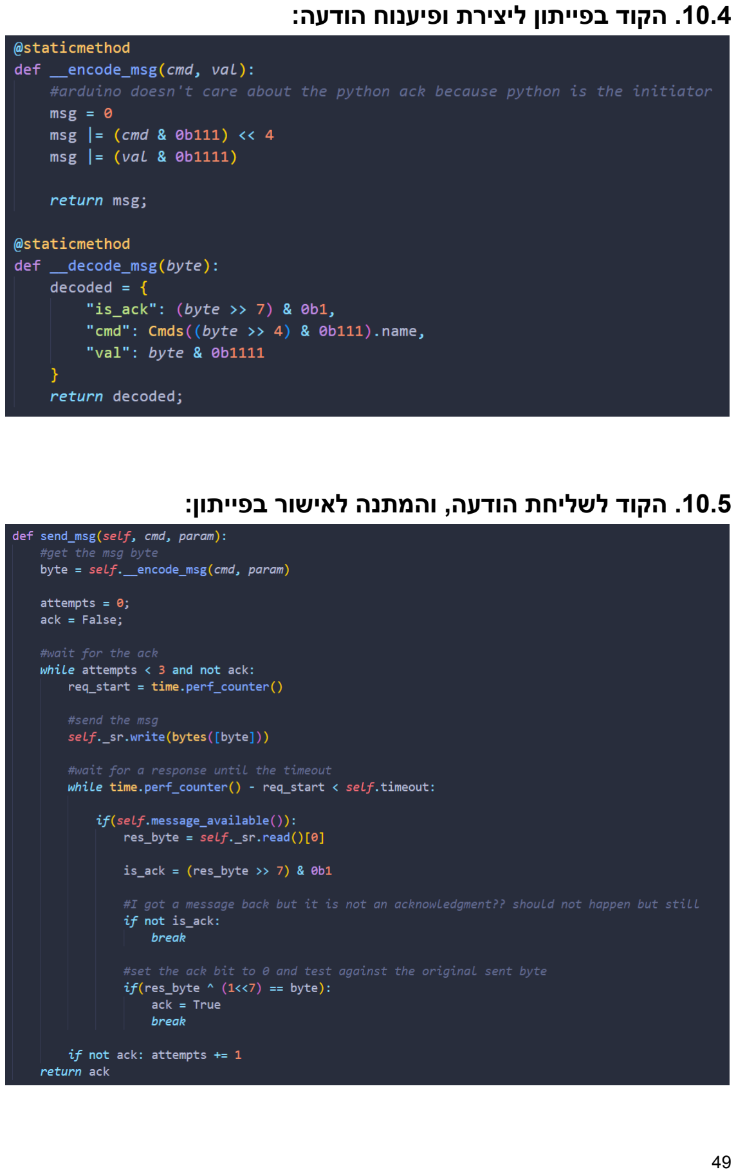
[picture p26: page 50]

## .10.5 הקוד לשליחת הודעה, והמתנה לאישור בפייתון:

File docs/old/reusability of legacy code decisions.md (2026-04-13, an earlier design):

# concerning the reusability of the code from [original project](https://github.com/Shumzi/Connect-4-Elephant-Robotics-Legacy)

1. Board.py: other than some irrlevant quirks, should be ok. might need to read a bit more about the ai to understand if we need to edit it or not.
2. ArmInterface - might just take out the relevant functions and throw out the rest.
3. Arduino stuff - need to use what Dekel and Max did, just need to organize it.
4. ai code - was based on some ai model that's irrelevent. Just reimplement from scratch/some os repo.

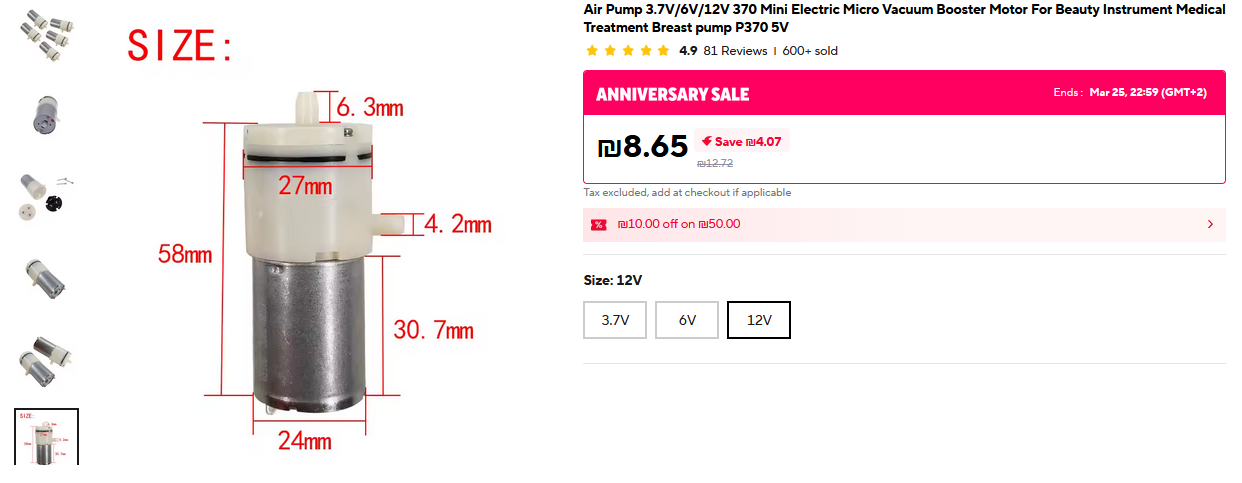
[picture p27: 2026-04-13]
docs/schematics and connections/pump driver/pump details.png

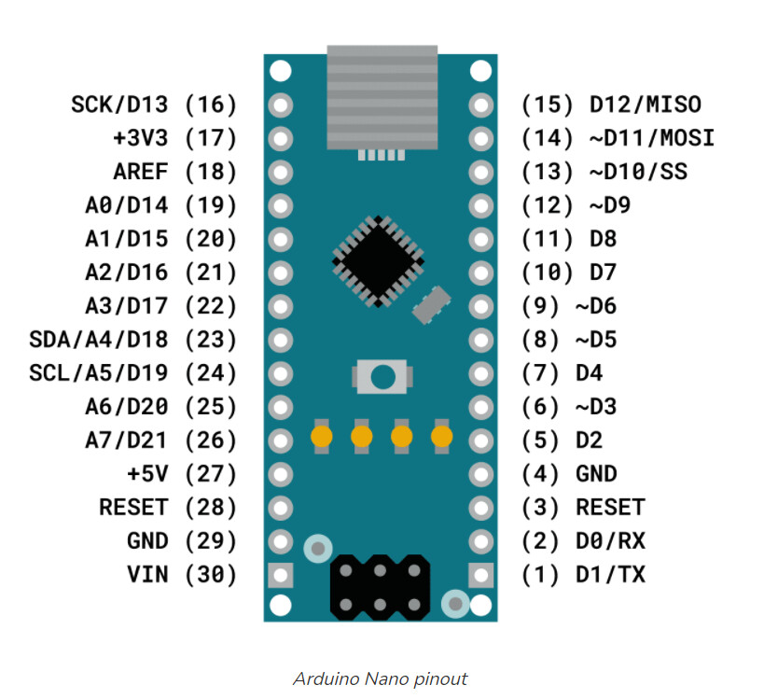
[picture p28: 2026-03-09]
docs/schematics and connections/arduino pins.jpeg

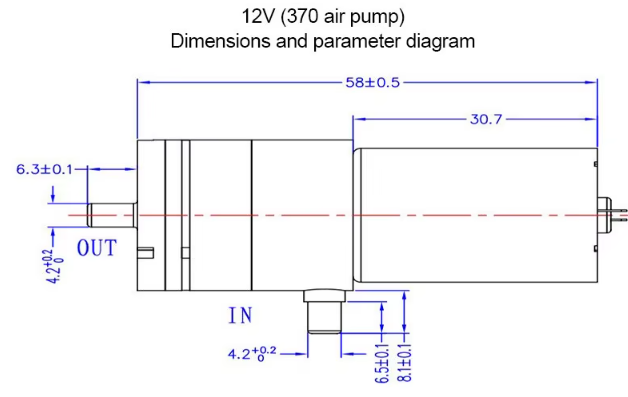
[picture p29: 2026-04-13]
docs/schematics and connections/pump driver/pump dimensions.png

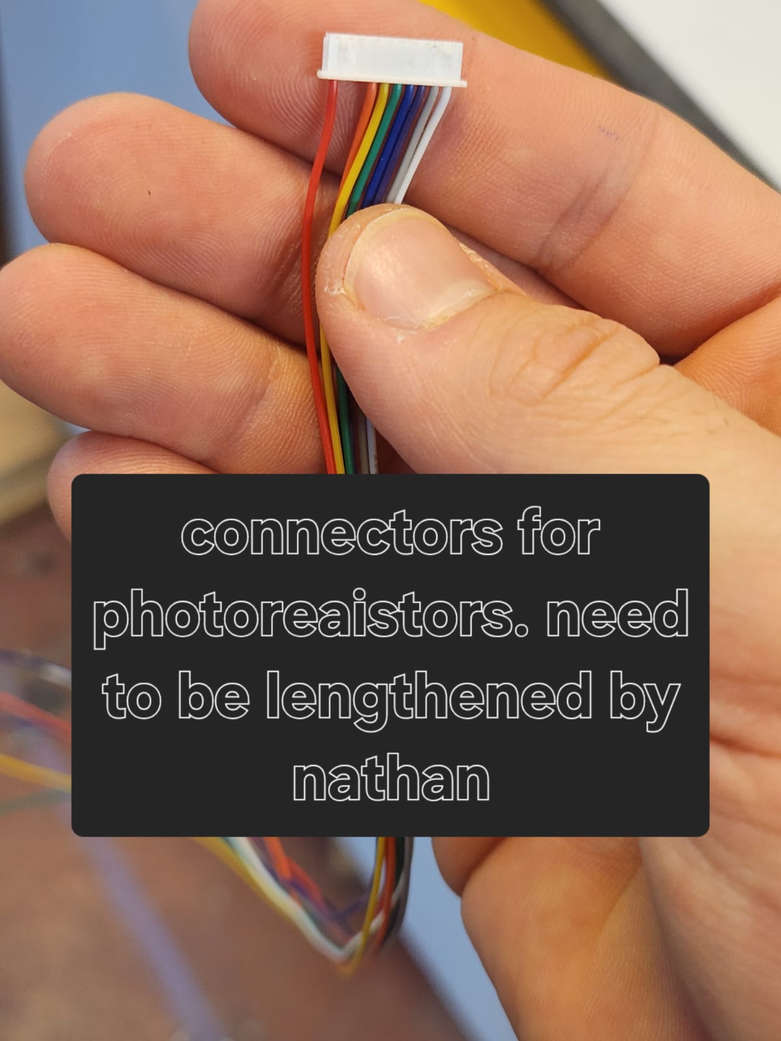
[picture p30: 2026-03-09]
docs/Photos/ledstrip connectors.jpg

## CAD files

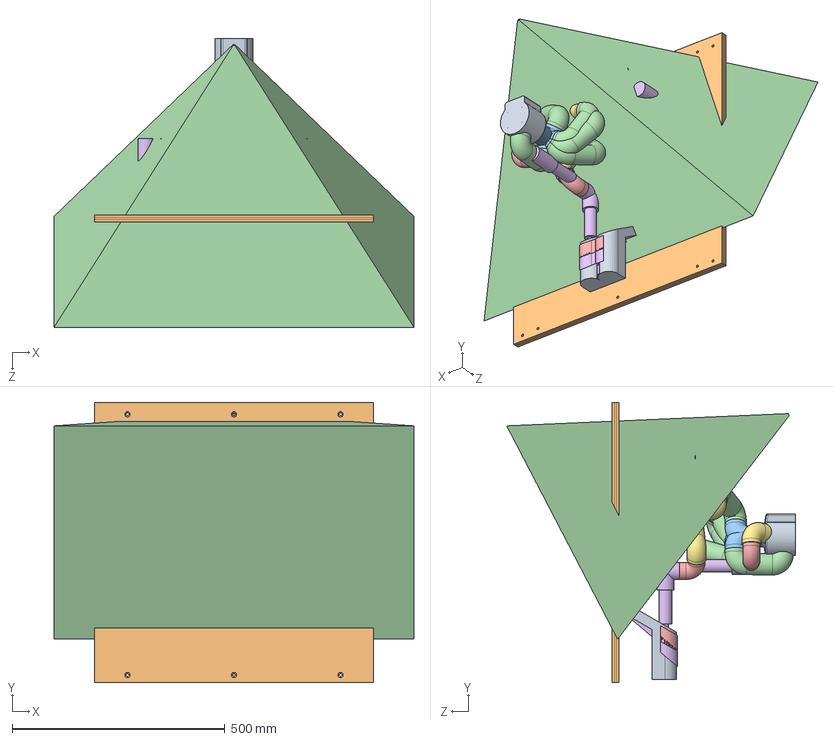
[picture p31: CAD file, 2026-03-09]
docs/DXF and SLDPRTs/sldprts/DEMO2.SLDASM
845.2 x 658.0 x 677.9 mm
wall05
baseArm x 5
lowerArm x 5
pitchArm x 5
rollArm x 5
upperArm x 5
basePlate x 5
Solenoid x 7
DISC RED x 39
DISC YLW x 27
stack window03

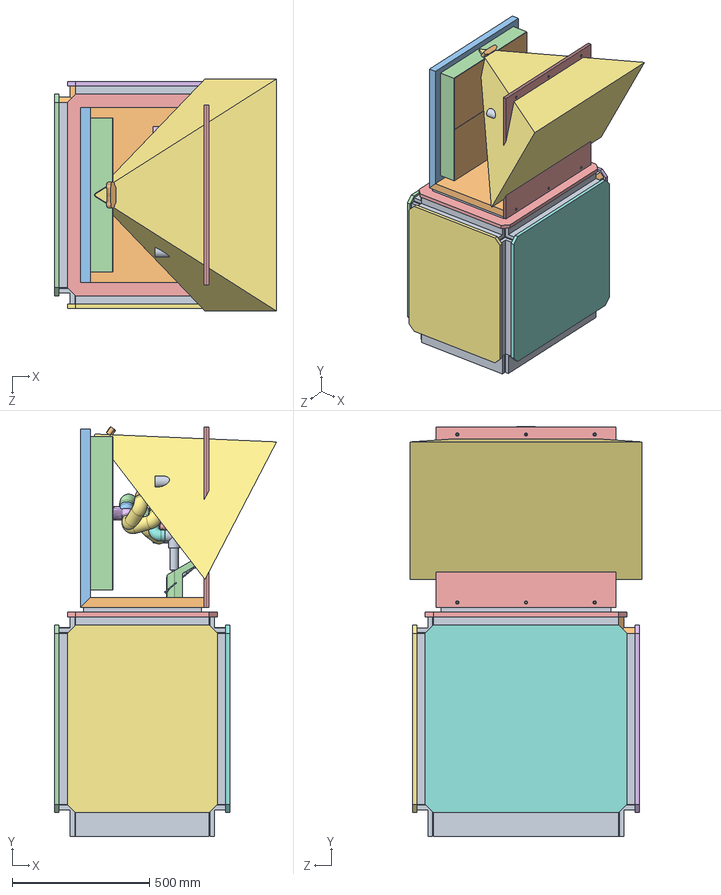
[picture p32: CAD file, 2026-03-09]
docs/DXF and SLDPRTs/sldprts/3D-ROB-010.SLDASM
808.9 x 1493.0 x 845.2 mm
Part2^3D-ROB-010
3D-BOX-007 x 2
3D-BOX-008
Part3^3D-ROB-010
Part4^3D-ROB-010
Part5^3D-ROB-010
Part6^3D-ROB-010
Part7^3D-ROB-010
Part9^3D-ROB-010
Part10^3D-ROB-010
Part11^3D-ROB-010
Part8^3D-ROB-010
Part13^3D-ROB-010 x 4
wall05
baseArm
lowerArm
pitchArm
rollArm
upperArm
basePlate
Solenoid x 7
DISC RED x 39
DISC YLW x 27
Logitech_C920
stack window04

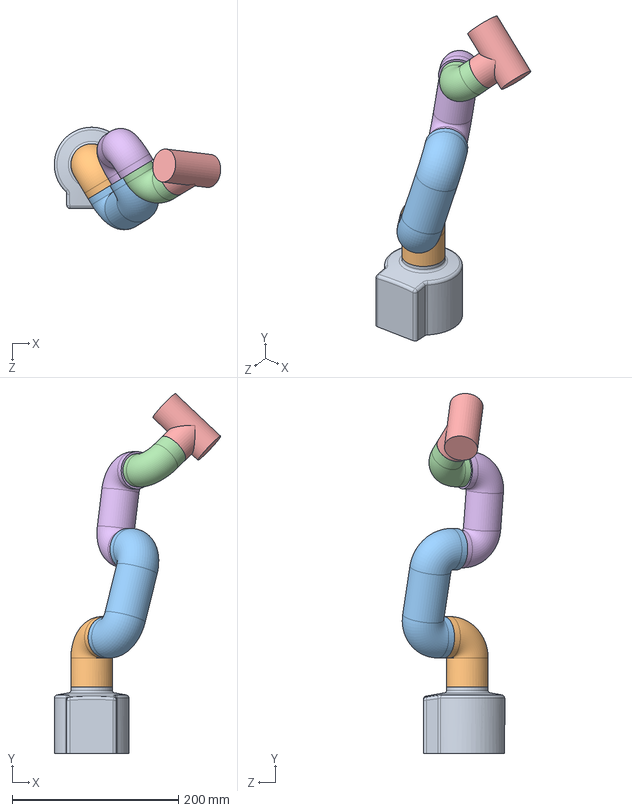
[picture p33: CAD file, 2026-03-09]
docs/DXF and SLDPRTs/sldprts/myCobotMK1.SLDASM
200.5 x 433.6 x 123.5 mm
baseArm
lowerArm
pitchArm
rollArm
upperArm
basePlate

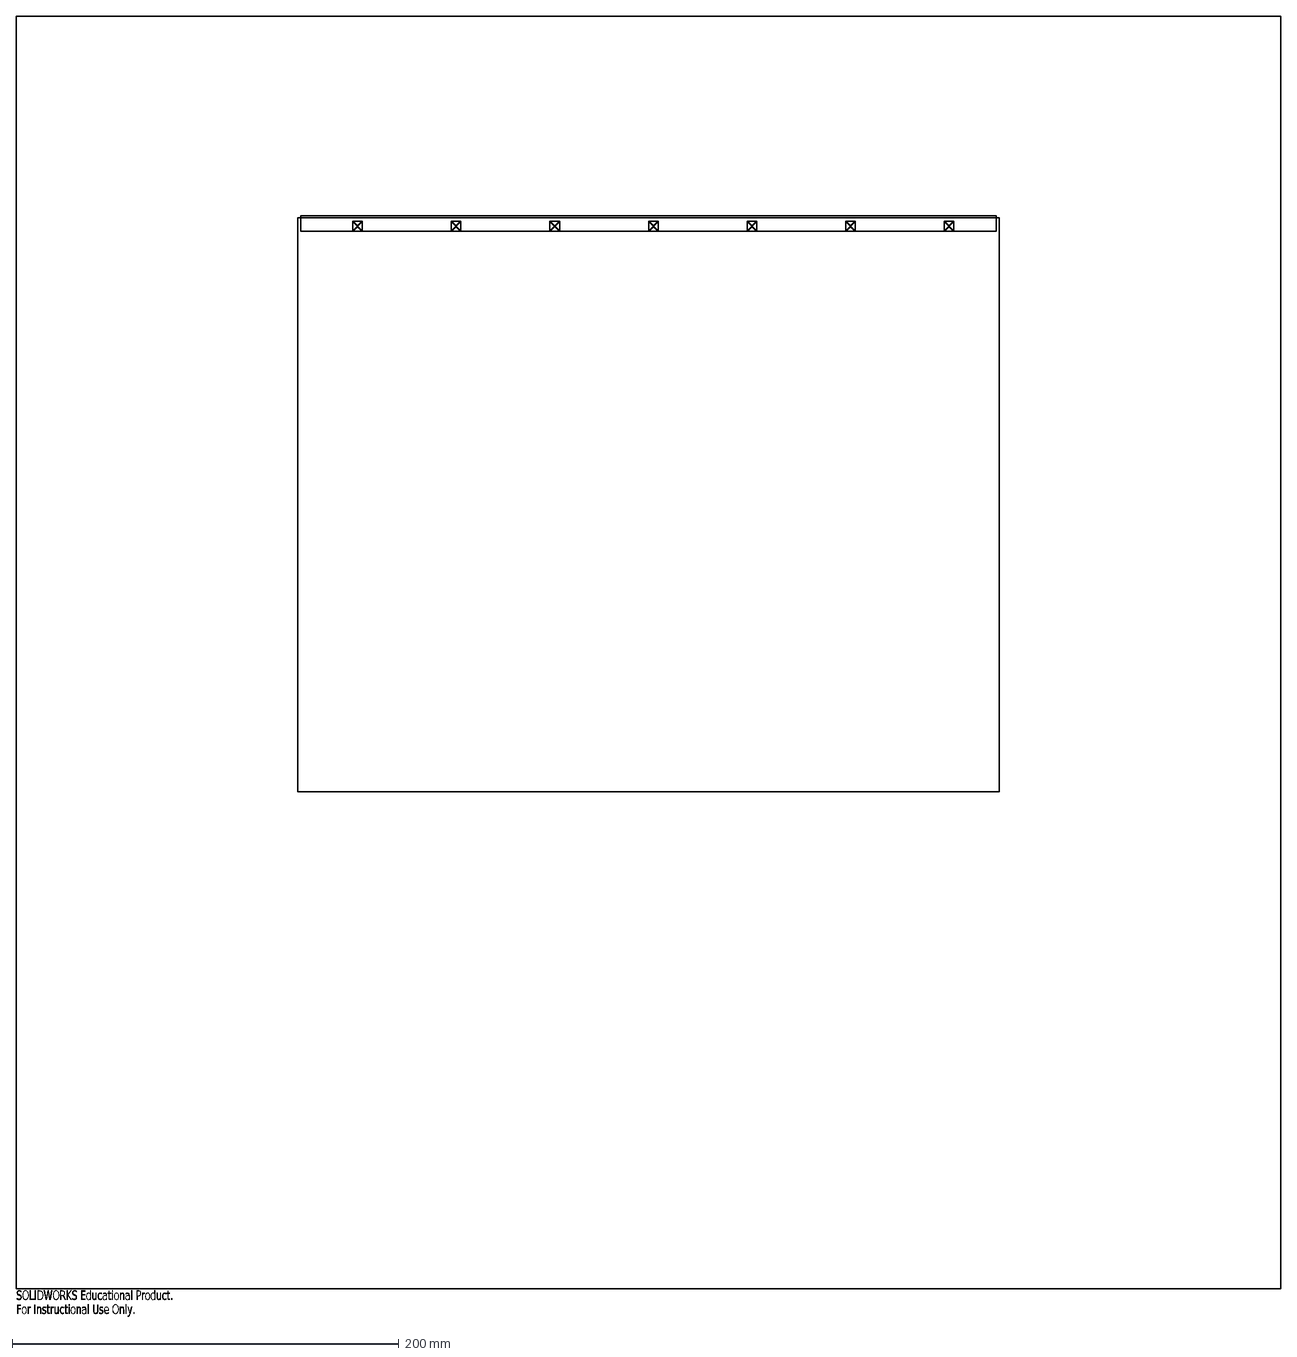
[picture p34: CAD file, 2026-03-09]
docs/DXF and SLDPRTs/Back DXF.DXF
SOLIDWORKS Educational Product.
For Instructional Use Only.

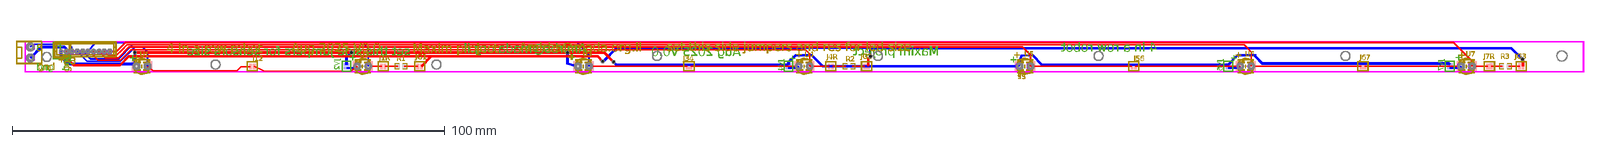
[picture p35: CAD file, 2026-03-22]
docs/schematics and connections/led strip (puck detection)/PCB_Robot_Led_Stripe_1.25mm_2026-03-18.dxf
4 in a row robot
Aug 2025 V0.0
Maxim project
Amirbs@mada.org.il
set this side jumpers for sensors size
+
gnd
3
set this side jumpers and res for led size
JV2
JV4
JV6
JV7
R1
R2
R3
U1
U2
U3
U4
L5
U5
U6
U7
S5
J1R
J4R
J7R
J34
J56
JG1
JG2
JG3
J12
J67

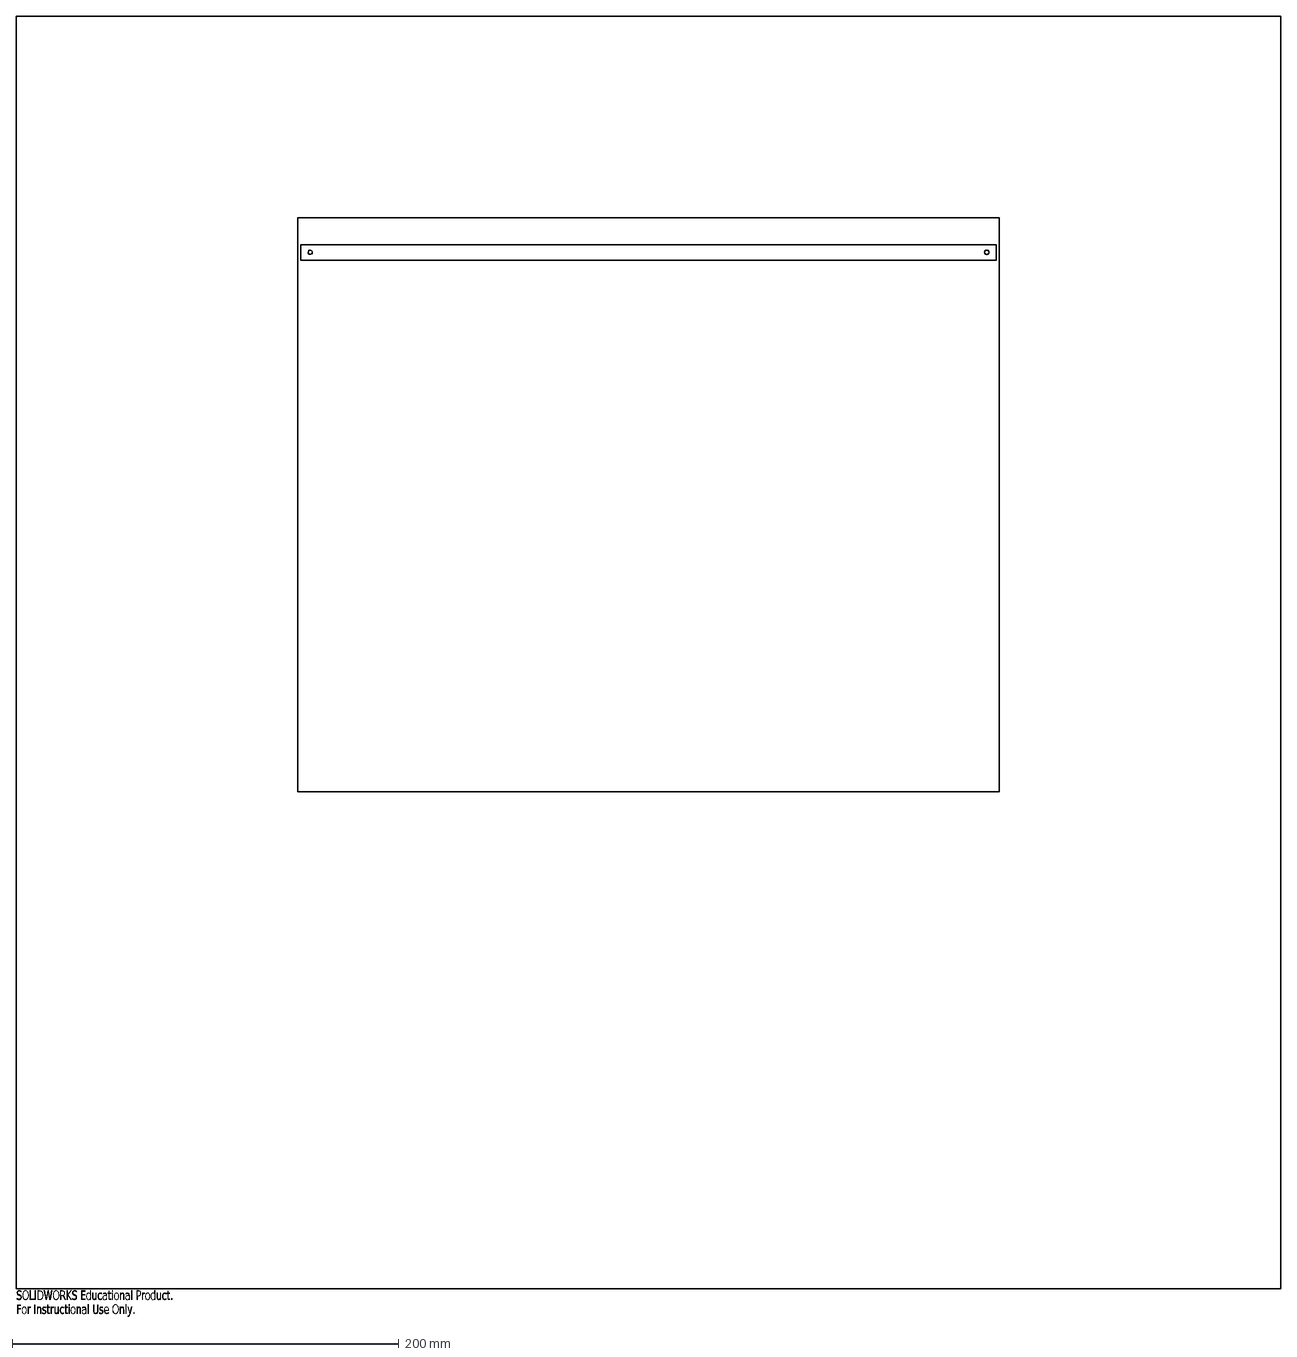
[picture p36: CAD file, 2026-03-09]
docs/DXF and SLDPRTs/front DXF.DXF
SOLIDWORKS Educational Product.
For Instructional Use Only.

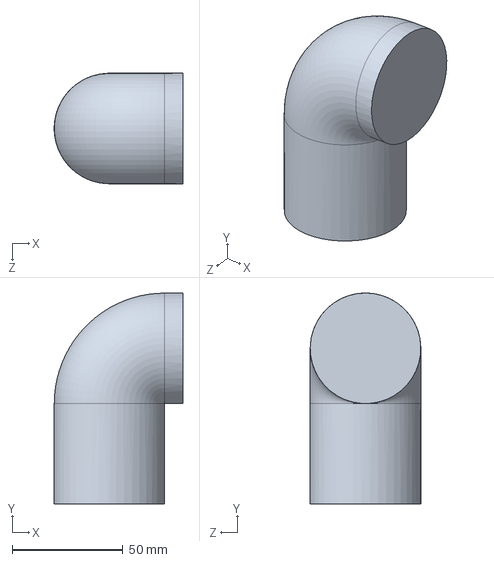
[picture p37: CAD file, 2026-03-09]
docs/DXF and SLDPRTs/sldprts/baseArm.SLDPRT
58.2 x 95.4 x 50.0 mm

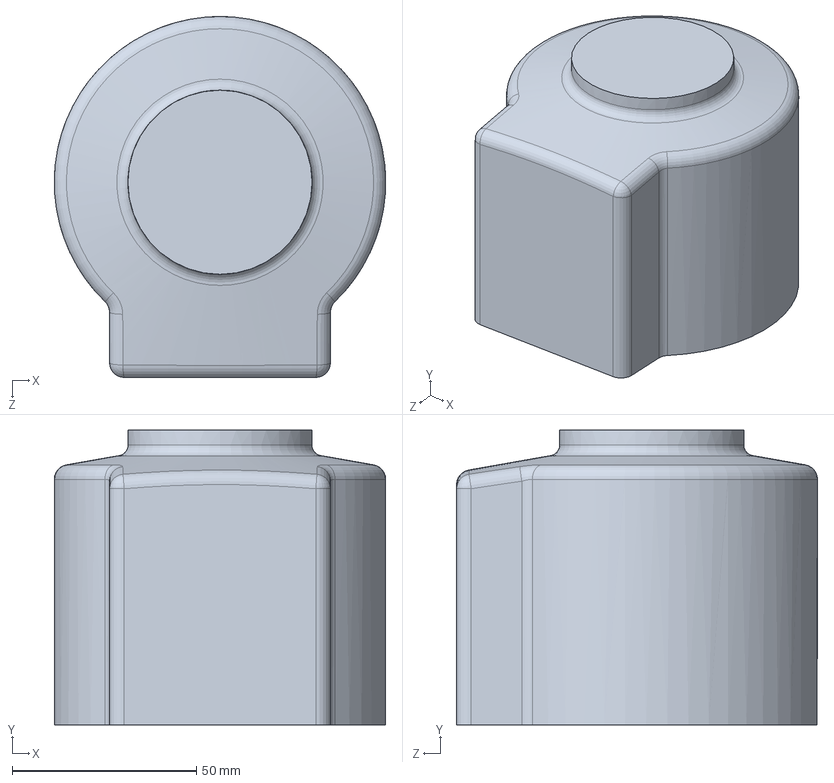
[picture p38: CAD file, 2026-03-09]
docs/DXF and SLDPRTs/sldprts/basePlate.SLDPRT
90.0 x 80.0 x 98.0 mm

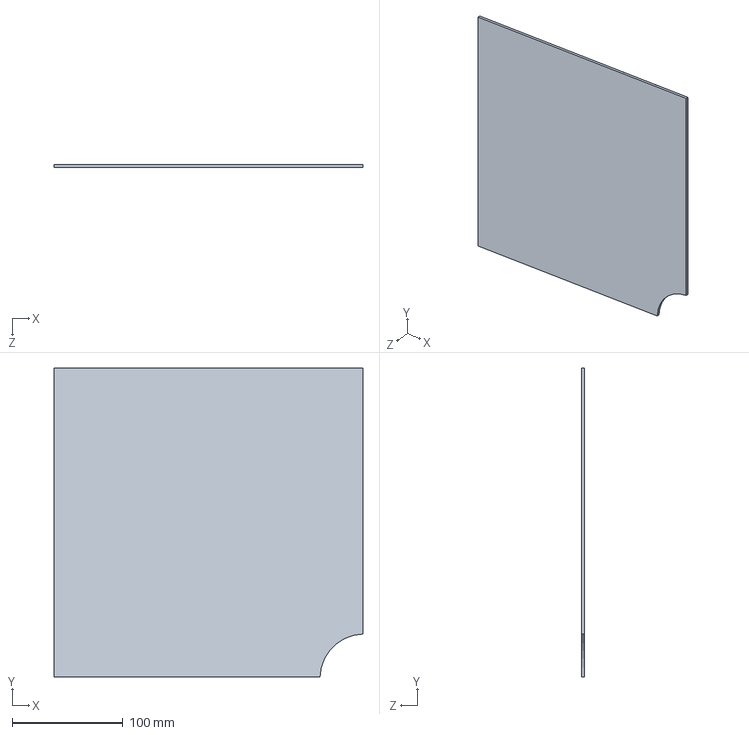
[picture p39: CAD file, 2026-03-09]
docs/DXF and SLDPRTs/sldprts/Part13^3D-ROB-010.SLDPRT
279.0 x 279.0 x 3.00 mm

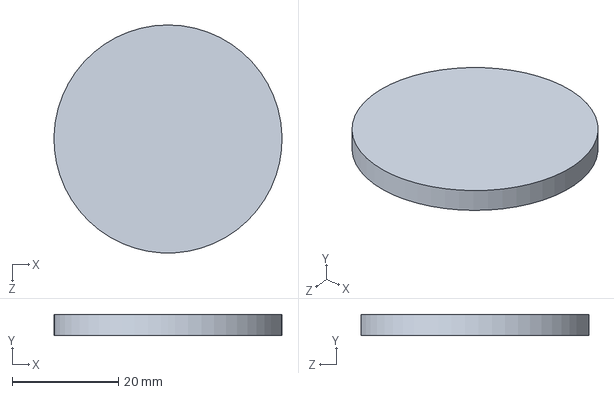
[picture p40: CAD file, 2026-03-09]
docs/DXF and SLDPRTs/sldprts/DISC RED.SLDPRT
43.0 x 4.00 x 43.0 mm

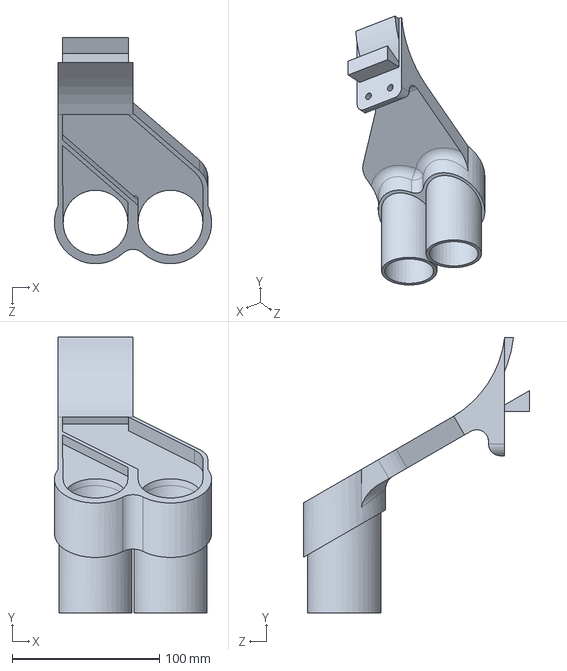
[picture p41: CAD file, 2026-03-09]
docs/DXF and SLDPRTs/sldprts/stack window02.SLDPRT
106.9 x 187.6 x 154.0 mm

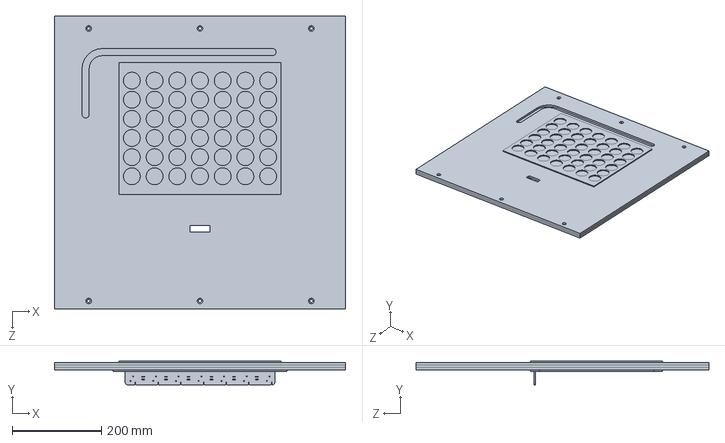
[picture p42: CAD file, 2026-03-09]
docs/DXF and SLDPRTs/sldprts/wall05.SLDPRT
654.0 x 53.0 x 658.0 mm

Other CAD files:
docs/DXF and SLDPRTs/sldprts/myCobotMK1(Default-_flexible1)-1.SLDASM
docs/DXF and SLDPRTs/sldprts/basePlate-1.SLDPRT
docs/DXF and SLDPRTs/sldprts/Part6^3D-ROB-010.SLDPRT
docs/DXF and SLDPRTs/sldprts/3D-ROB-003.SLDPRT
docs/DXF and SLDPRTs/sldprts/Part9^3D-ROB-010.SLDPRT
docs/DXF and SLDPRTs/sldprts/Part5^3D-ROB-010.SLDPRT
docs/DXF and SLDPRTs/sldprts/3D-BOX-007.SLDPRT
docs/DXF and SLDPRTs/sldprts/3D-BOX-008.SLDPRT
docs/DXF and SLDPRTs/sldprts/3D-ROB-001.SLDPRT
docs/DXF and SLDPRTs/sldprts/3D-ROB-002.SLDPRT
docs/DXF and SLDPRTs/sldprts/3D-ROB-004.SLDPRT
docs/DXF and SLDPRTs/sldprts/DISC YLW.SLDPRT
docs/DXF and SLDPRTs/sldprts/FOV.SLDPRT
docs/DXF and SLDPRTs/sldprts/Logitech_C920.SLDPRT
docs/DXF and SLDPRTs/sldprts/Part10^3D-ROB-010.SLDPRT
docs/DXF and SLDPRTs/sldprts/Part11^3D-ROB-010.SLDPRT
docs/DXF and SLDPRTs/sldprts/Part12^3D-ROB-010.SLDPRT
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

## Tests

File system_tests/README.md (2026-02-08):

# System tests

Run from **project root** (Connect-4-Robot).

## 1. Game AI (text-only play)

No Arduino or robot. Play Connect 4 against the AI in the terminal.

```bash
python -m system_tests.play_ai_text
```

Enter column 0–6 or `quit`. After each game you can play again.

## 2. Robot location test

Runs the arm through a safe sequence; after each step you enter **edit mode**:

- **1** / **2**: nudge +X / -X (mm)
- **3** / **4**: nudge +Y / -Y
- **5** / **6**: nudge +Z / -Z
- **r**: release servos (move arm by hand)
- **l**: lock servos
- **v**: save current position to the step and write JSON
- **n**: next step (no save)

```bash
python -m system_tests.test_robot_locations --port COM11
python -m system_tests.test_robot_locations --port COM11 --json-path path/to/robot_locations.json
python -m system_tests.test_robot_locations --port COM11 --no-edit   # run sequence only, no edit mode
```

## 3. Arduino tests

**LED detection** – serial monitor for `DROP <col>` and `START`:

```bash
python -m system_tests.test_arduino led --port COM5
```

**Solenoids** – send OPEN, then CLOSE; optionally RESET:

```bash
python -m system_tests.test_arduino solenoids --port COM5
python -m system_tests.test_arduino solenoids --port COM5 --reset
```

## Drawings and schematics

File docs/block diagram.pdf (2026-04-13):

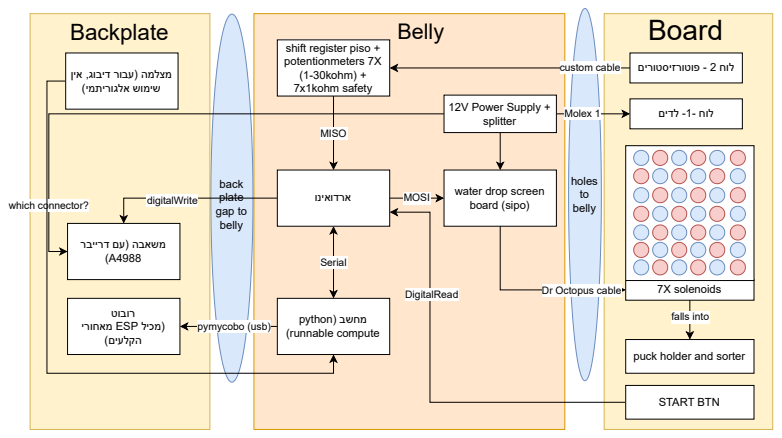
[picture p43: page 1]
back plate gap to; holes to belly; Backplate; Belly; Serial; ארדואינו digitalWrite; board; MISO; shift register piso + potentionmeters 7X (1-30kohm) + 7x1kohm safety; custom cable; Molex 1; which connector?; 12V Power Supply + splitter; pymycobo (usb); python(; מחשב; )runnable compute; MOSI; water drop screen; board (sipo); falls into; 7X solenoids; לוח -1- לדים; לוח 2 - פוטורזיסטורים; Board; DigitalRead; START BTN

מצלמה )עבור דיבוג, אין
שימוש אלגוריתמי(

belly

משאבה )עם דרייבר

Dr Octopus cable

רובוט
)מכיל ESP מאחורי
הקלעים(

puck holder and sorter

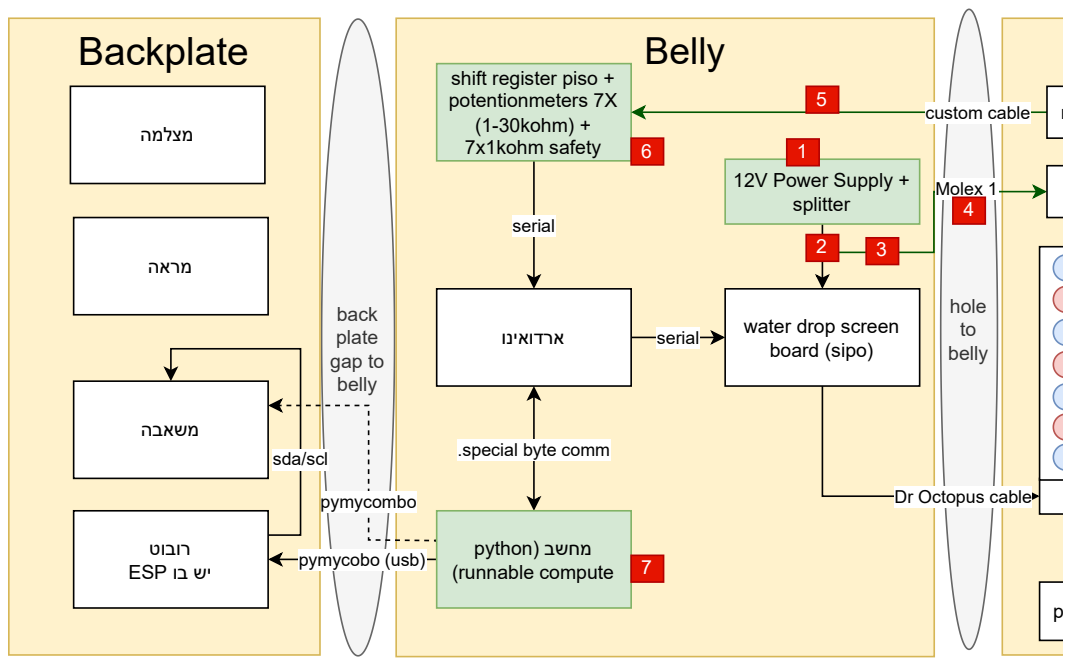
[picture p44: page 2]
back plate gap to belly; Backplate; Belly; ארדואינו; serial; shift register piso + potentionmeters 7X (1-30kohm) + 7x1kohm safety; custom cable; Molex 1 12V Power Supply + splitter; pymycobo (usb); pymycombo; מחשב )python )runnable compute; water drop screen; board (sipo); מראה; מצלמה

hole to belly

משאבה

.special byte comm sda/scl

Dr Octopus cable

רובוט
יש בו ESP

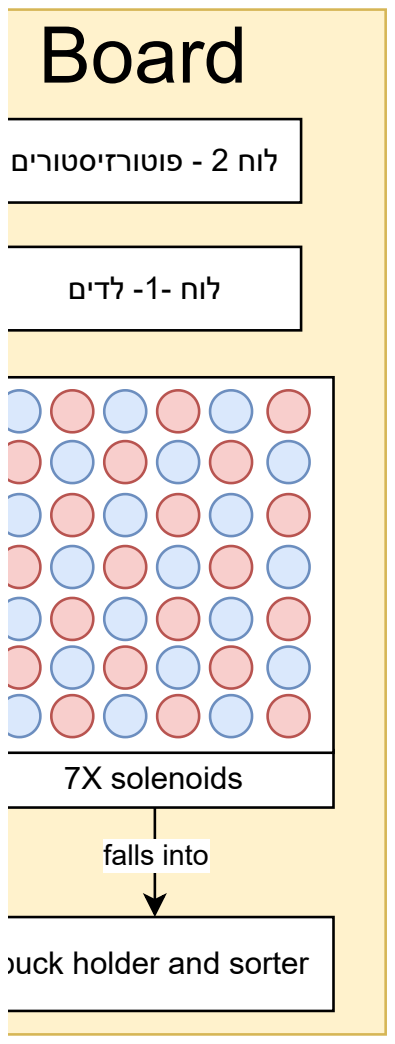
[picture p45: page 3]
board; falls into; 7X solenoids; לוח -1- לדים; לוח 2 - פוטורזיסטורים; Board

puck holder and sorter

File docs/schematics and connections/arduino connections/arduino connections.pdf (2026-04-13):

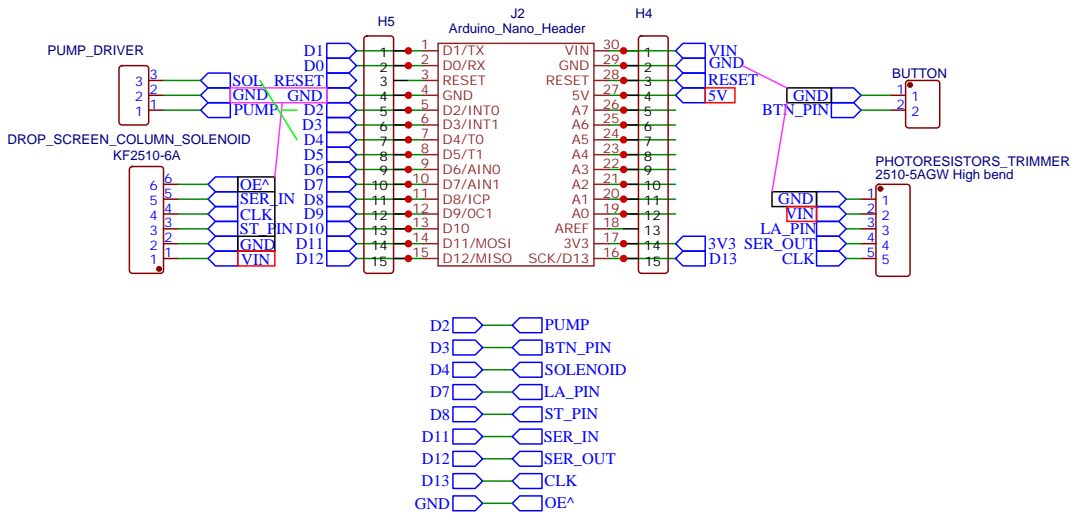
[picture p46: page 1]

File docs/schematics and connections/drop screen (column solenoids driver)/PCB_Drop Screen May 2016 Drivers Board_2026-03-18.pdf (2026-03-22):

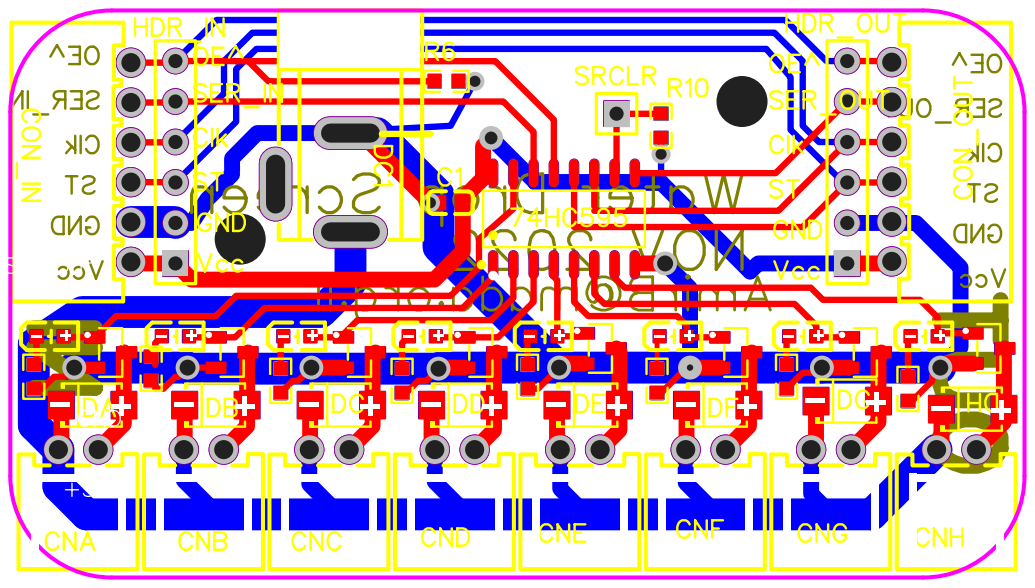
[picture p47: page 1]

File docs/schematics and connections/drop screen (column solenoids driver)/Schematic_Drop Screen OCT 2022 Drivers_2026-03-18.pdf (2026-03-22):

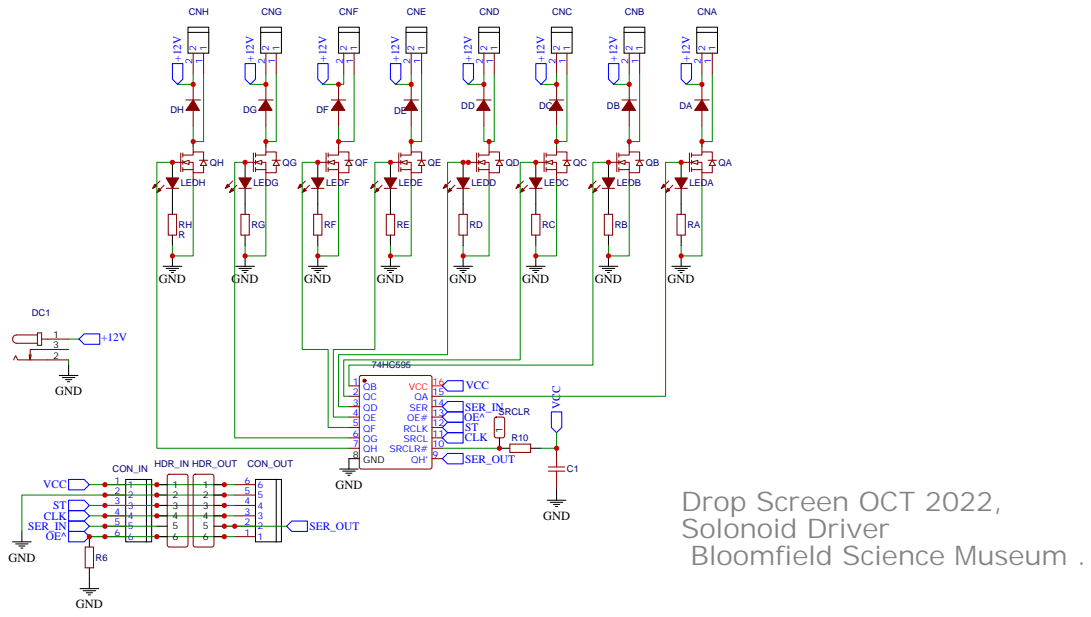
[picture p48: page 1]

SRCLR# 10 SRCL 11 RCLK 12 OE# 13 SER 14 QA 15 VCC 16

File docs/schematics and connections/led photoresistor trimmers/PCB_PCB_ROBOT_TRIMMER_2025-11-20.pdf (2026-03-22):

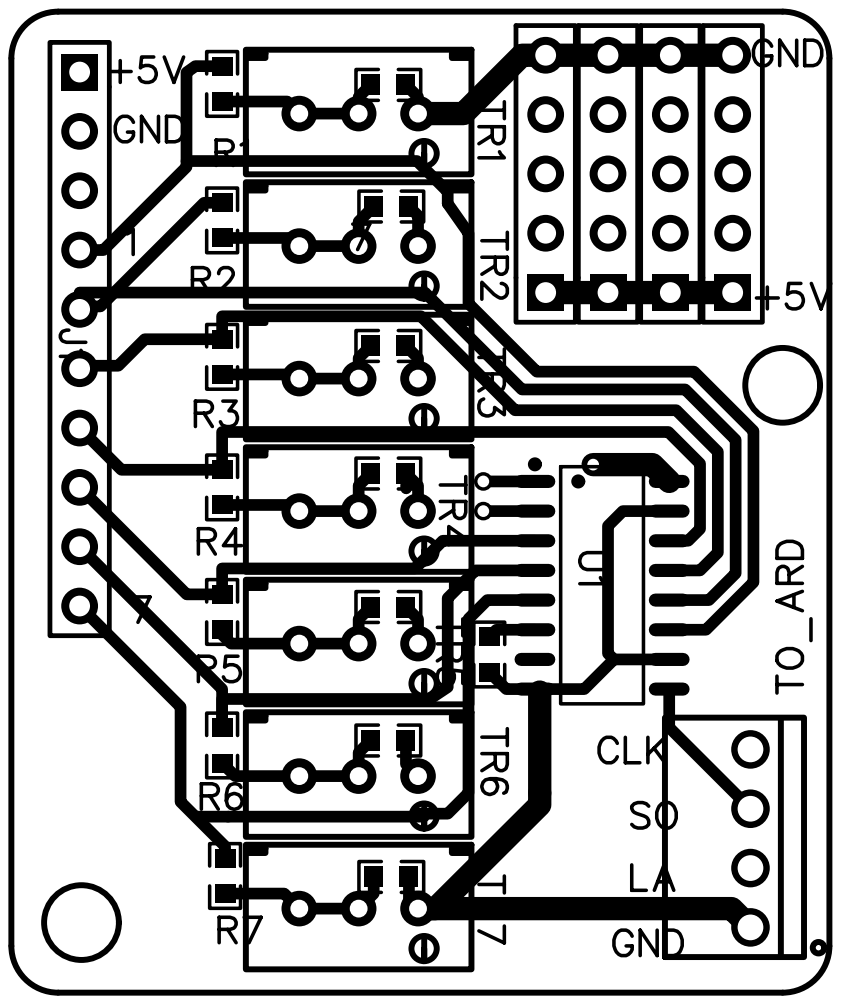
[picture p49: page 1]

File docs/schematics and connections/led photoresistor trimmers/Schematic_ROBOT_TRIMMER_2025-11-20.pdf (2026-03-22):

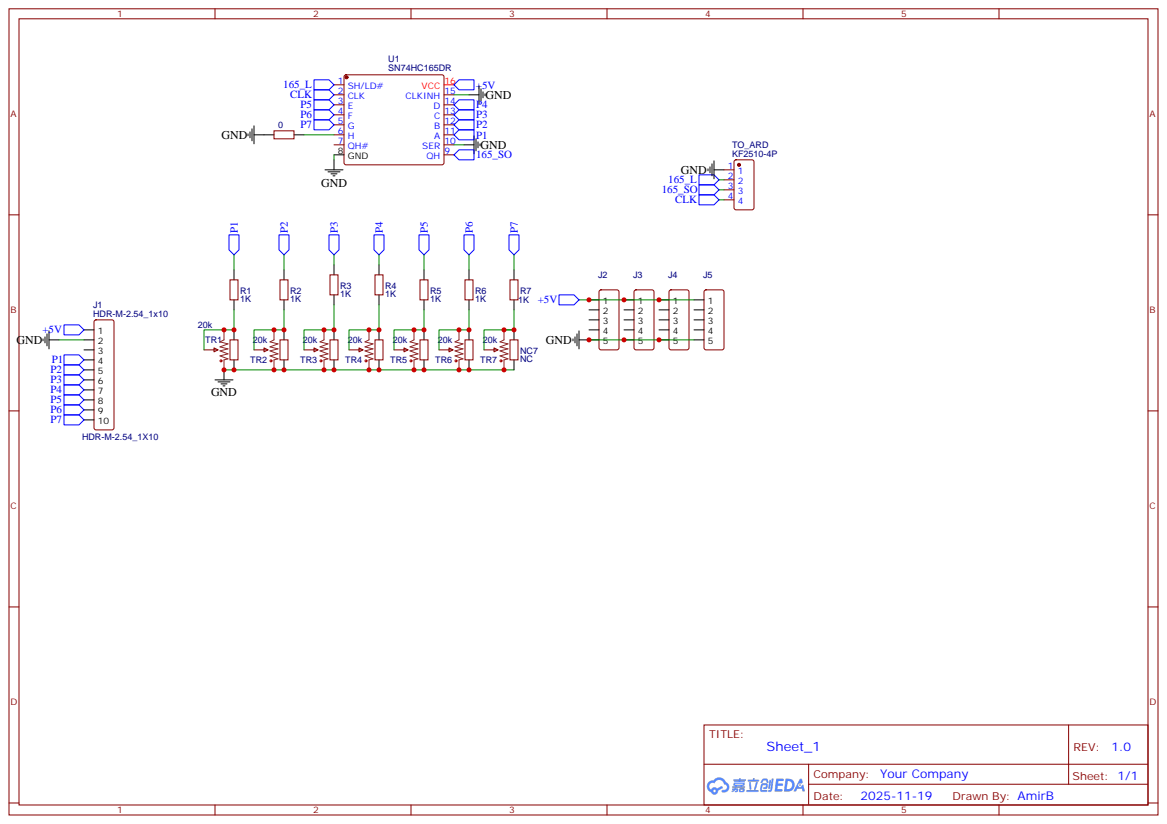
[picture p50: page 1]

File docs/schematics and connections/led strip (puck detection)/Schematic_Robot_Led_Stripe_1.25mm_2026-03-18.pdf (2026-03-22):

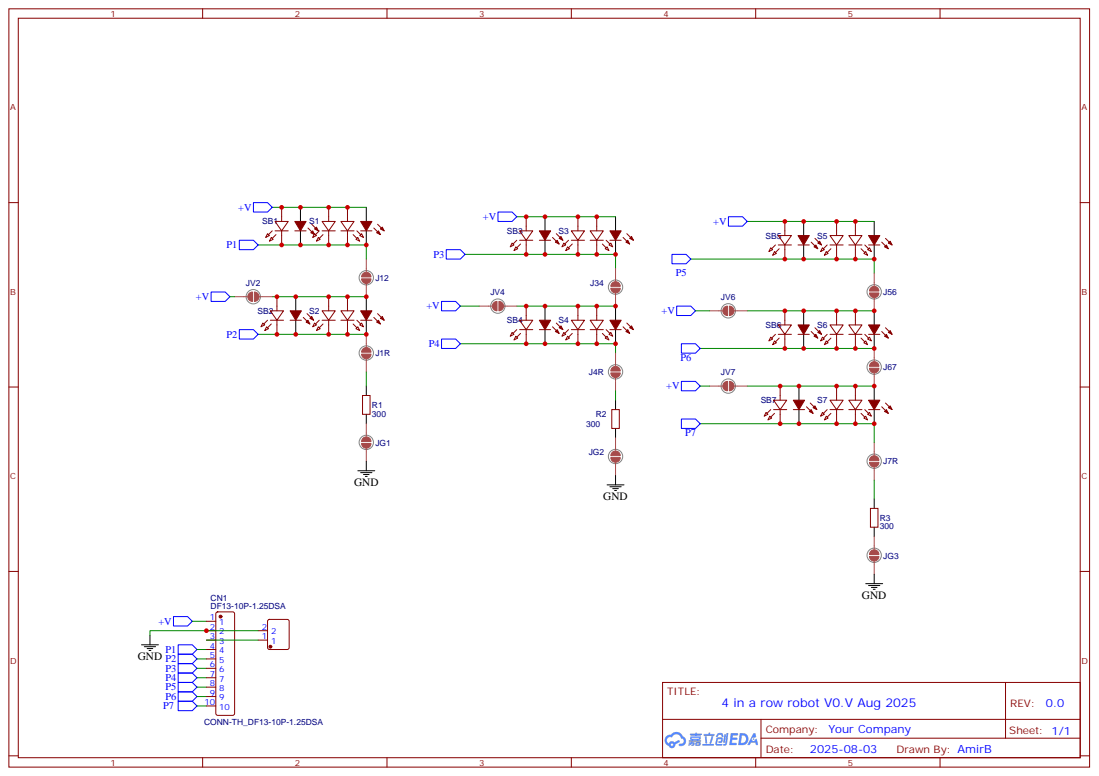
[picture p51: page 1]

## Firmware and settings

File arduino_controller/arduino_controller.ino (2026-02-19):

#include <SPI.h>
#include <stdint.h>
#include "sensor_handler.h"

#define PUCK_ANALOG_PIN A2

void setup() {
  Serial.begin(115200);
  Serial.println("LOG setting up");
  setup_sensors();

  SPI.begin();
  SPI.beginTransaction(SPISettings(1000000, MSBFIRST, SPI_MODE0));
  close_solenoids();
  delay(1000);
  Serial.println("LOG set up");
  Serial.println("START");
}


void loop() {
  handleDiscDetection();
  handleButtonPress();
  if (Serial.available()) {
    handle_cmd(Serial.readStringUntil('\n'));
  }
}

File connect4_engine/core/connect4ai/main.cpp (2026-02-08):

/*
 * This file is part of Connect4 Game Solver <http://connect4.gamesolver.org>
 * Copyright (C) 2017-2019 Pascal Pons <contact@gamesolver.org>
 *
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
 * You should have received a copy of the GNU Affero General Public License
 * along with Connect4 Game Solver. If not, see <http://www.gnu.org/licenses/>.
 */

#include "Solver.hpp"
#include <iostream>
#include <algorithm>


using namespace GameSolver::Connect4;

/**
 * Main function.
 * Reads Connect 4 positions, line by line, from standard input
 * and writes one line per position to standard output containing:
 *  - score of the position
 *  - number of nodes explored
 *  - time spent in microsecond to solve the position.
 *
 *  Any invalid position (invalid sequence of move, or already won game)
 *  will generate an error message to standard error and an empty line to standard output.
 */
int main(int argc, char** argv) {
  Solver solver;
  bool weak = false;
  bool analyze = false;

  std::string opening_book = "7x6.book";
  for(int i = 1; i < argc; i++) {
    if(argv[i][0] == '-') {
      if(argv[i][1] == 'w') weak = true; // parameter -w: use weak solver
      else if(argv[i][1] == 'b') { // paramater -b: define an alternative opening book
        if(++i < argc) opening_book = std::string(argv[i]);
      }
      else if(argv[i][1] == 'a') { // paramater -a: make an analysis of all possible moves
        analyze = true;
      }
    }
  }
  solver.loadBook(opening_book);

  std::string line;

  for(int l = 1; std::getline(std::cin, line); l++) {
    Position P;
    if(P.play(line) != line.size()) {
      std::cerr << "Line " << l << ": Invalid move " << (P.nbMoves() + 1) << " \"" << line << "\"" << std::endl;
    } else {
      // std::cout << line;
      if(analyze) {
        std::vector<int> scores = solver.analyze(P, weak);
        for (const int& score : scores) {
          std::cout << score << " ";
        }
        std::cout << std::endl;
      }
      else {
        int score = solver.solve(P, weak);
        // std::cout << " " << score;
      }
      // std::cout << std::endl;
    }
  }
}

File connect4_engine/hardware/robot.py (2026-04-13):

from abc import ABC, abstractmethod
import threading
import time
import json

import numpy as np
from pymycobot import MyCobot280

from connect4_engine.utils.config import get_config
from connect4_engine.utils.logger import logger, timed
from connect4_engine.hardware.arduino import ArduinoCommunicator as Arduino

class IRobot(ABC):

    @abstractmethod
    def drop_piece(self, column: int, puck_no: int):
        """
        Drop a puck in the specified column, given that it's the nth puck.
        Args:
            column: int - the column to drop the puck in
            puck_no: int - the number of the puck to drop (from red stack.)
        Returns:
            None
        """
        pass
    
    @abstractmethod
    def give_player_puck(self, puck_no: int):
        """
        Give player a yellow puck from that stack, given that it's the nth pucki.
        Args:
            puck_no: int - the number of the puck to drop (from yellow stack.)
        Returns:
            None
        """
        pass

    @abstractmethod
    def reset(self):
        pass


class RobotCommunicator(IRobot):
    def __init__(self, com_port: str | None, pump: Arduino = None, coord_json: dict = None, json_path: str = None):
        if pump is None:
            raise ValueError("pump must be provided")
        self.pump = pump
        self.mc = MyCobot280(com_port)
        if coord_json is not None:
            self.coord_json = coord_json
        elif json_path is not None:
            with open(json_path, "r") as f:
                self.coord_json = json.load(f)
        else:
            self.coord_json = json.load(open("connect4_engine/hardware/legacy_coords.json"))
        self.ARM_SPEED = 100
        self.ARM_SPEED_PRECISE = 50
        self.MOVE_TIMEOUT = 1
        self.DISK_LEVEL_Y = self.coord_json['DISK_DELTA_FROM_HOVER_Y']
        self.DISK_LEVEL_R = self.coord_json['DISK_DELTA_FROM_HOVER_R']
        self.killswitch = threading.Event()
        robo_config = get_config()["hardware"]["robot"]
        self.pause_between_moves = robo_config['pause_between_moves']
        # Define angle tables for different positions
        self.angle_table = self.coord_json["angle_table"]

        # Define chess table for different positions
        self.chess_table = self.coord_json["chess_table"]
        
        # Define drop table for different positions
        self.drop_table = self.coord_json["drop_table"]
    
    # Method to send angles with retry logic
    def send_angles(self, angle, speed):
        self.check_exit()
        self.mc.sync_send_angles(angle, speed, self.MOVE_TIMEOUT)
        for tries in range(3):
            self.check_exit()
            if not self.mc.is_in_position(angle, 0):
                self.mc.sync_send_angles(angle, speed, self.MOVE_TIMEOUT)
        if(self.pause_between_moves):
            input('press <Enter> to proceed.')

    # check if you should ky
    def check_exit(self):
        if(self.killswitch.is_set()):
            logger.error("thread requested exit, going back to observe and exit.")
            # TODO: return puck to place if i'm still holding something.
            self.mc.sync_send_coords(self.angle_table["observe"], self.ARM_SPEED)
            self.killswitch.clear()
            logger.error("exit robot thread")
            raise SystemExit
        
    # Method to send coords with retry logic   
    @timed 
    def send_coords(self, target_coords, speed, mode = 0, step_per_mm = 50):
        """
        send coords in a synced fashion. use custom linear func for linear motion as mycobot's linear mode is bad.
        """
        logger.debug(f"GOING TO {target_coords}")
        self.check_exit()
        if(mode == 1):
            coordlist = self.get_coords_interpolated(target_coords, step_per_mm)
        else:
            coordlist = [target_coords]
        for waypoint in coordlist:
            self.mc.sync_send_coords(waypoint, speed, 0, self.MOVE_TIMEOUT)
            # we can only hope for the best in terms of calibration. 
            # mi yiten vekol mishaloteinu yitkablu bivracha.
            # for tries in range(3):
            #     self.check_exit()
            #     is_in_pos = self.mc.is_in_position(waypoint, 1)
            #     if not is_in_pos:
            #         logger.debug(f'try no {tries} bc mc in position gave {is_in_pos}')
            #         self.mc.sync_send_coords(waypoint, speed, 0, self.MOVE_TIMEOUT)
            if(self.pause_between_moves):
                input('press <Enter> to proceed.')

    def get_coords_interpolated(self, target_coords, step_mm):
        """get list of interpolated waypoints from current position to target (incl.)
        Only interpolates x, y, z; rx, ry, rz are taken from target_coords.
        Computes number of waypoints so each step is ~step_mm apart.
        replaces the bad linear motion supplied by mycobot."""
        import math
        self.check_exit()
        start = self.get_current_coords()
        print(f'start: {start[:3]}\nend:   {list(target_coords[:3])}')
        dist = math.sqrt(sum((target_coords[j] - start[j]) ** 2 for j in range(3)))
        num_points = max(1, round(dist / step_mm))
        print(f'dist: {dist}. numpoints: {num_points}')
        self.check_exit()
        waypoints = []
        for i in range(1, num_points + 1):
            t = i / num_points
            waypoint = [
                start[j] + (target_coords[j] - start[j]) * t
                for j in range(3)
            ] + list(target_coords[3:])
            waypoints.append(waypoint)
        return waypoints
    # test

    def get_current_angles(self):
        """Return current joint angles (for location edit flow)."""
        return self.mc.get_angles()

    def get_current_coords(self):
        """Return current Cartesian coords [x, y, z, rx, ry, rz] (for location edit flow)."""
        return self.mc.get_coords()

    def release_servos(self):
        """Release all servos so the arm can be moved by hand."""
        self.mc.release_all_servos()

    def lock_servos(self):
        """Re-engage servos at current position (call after release_servos)."""
        angles = self.get_current_angles()
        if angles is not None and len(angles) == 6:
            self.send_angles(angles, self.ARM_SPEED)

    # Method to pass to the prepare position
    def prepare(self):
        self.send_angles(self.angle_table["prepare"], self.ARM_SPEED)
                
    # Method to return to the initial position
    def recovery(self):
        self.send_angles(self.angle_table["recovery"], self.ARM_SPEED)

    # Method to move to the top of the left discs stack
    def hover_over_stack_red(self):
        self.send_coords(self.angle_table["stack-hover-red"], self.ARM_SPEED_PRECISE, 0)
    
    # Method to move to in front of left discs stack
    def apro_stack_red(self):
        self.send_coords(self.angle_table["stack-apro-red"], self.ARM_SPEED,0)
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

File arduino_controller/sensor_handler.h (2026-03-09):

#include "Arduino.h"
#pragma once 

#include <SPI.h>
#include <stdint.h>
#include <string.h>
/*
*
*==========Arduino Nano pinout====== 
 *                            _______
 *                       TXD-|       |-Vin 
 *                       RXD-|       |-Gnd  
 *                       RST-|       |-RST
 *                       GND-|       |-+5V  
 *              PUMP_PIN  D2-|       |-A7  
 *               BTN_PIN  D3-|       |-A6  
 *          SOLENOID_PIN  D4-|       |-A5   
 *                        D5-|       |-A4  
 *                        D6-|       |-A3   
 *         LA_PIN (MISO)  D7-|       |-A2  
 *          ST_PIN (MOSI) D8-|       |-A1   
 *                        D9-|       |-A0   
   *                     D10-|       |-Ref
 *               SER_IN  D11-|       |-3.3V   
 *              SER_OUT  D12-|       |-D13 CLK (SPI)
 *                            --USB--        
 */

#define PUMP_PIN 2
#define BTN_PIN 3      //The start button 
#define SOLENOID_PIN 4 // release pump w solenoid
#define LA_PIN 7     //165 - read from photoresistors
#define ST_PIN 8    //595 - write for solenoids


const int DEBOUNCE_MS = 1000;
const int ms_to_reset = 2000; // no. of ms user needs to press button to reset the game.
unsigned long last_change_ms = 0;
byte solenoid_state = 0;

// Timing variables
unsigned long pumpStartTime = 0;
const unsigned long pumpTimeout = 30000UL;  // 30 seconds in ms
bool pumpRunning = false;

void setup_sensors()
{
  pinMode(ST_PIN, OUTPUT);
  pinMode(LA_PIN, OUTPUT);
  pinMode(BTN_PIN, INPUT_PULLUP);
  pinMode(PUMP_PIN, OUTPUT);
  pinMode(SOLENOID_PIN, OUTPUT);
  digitalWrite(LA_PIN, HIGH);
  digitalWrite(ST_PIN, HIGH);
  digitalWrite(PUMP_PIN, LOW);
  digitalWrite(SOLENOID_PIN, LOW);
}

void writeToSr(byte data) {
  digitalWrite(ST_PIN, LOW);
  SPI.transfer(data);             // Send output byte
  digitalWrite(ST_PIN, HIGH);  // Latch output
}


void turnOnPump() {
  digitalWrite(PUMP_PIN, HIGH);
  digitalWrite(SOLENOID_PIN, LOW);
  Serial.println("LOG: PUMP ON");
  pumpStartTime = millis();
  pumpRunning = true;
}

void shutOffPump() {

  digitalWrite(PUMP_PIN, LOW);
  digitalWrite(SOLENOID_PIN, LOW);
  pumpRunning = false;
  Serial.println("LOG: PUMP OFF");

}

void releasePump() {
  digitalWrite(PUMP_PIN, LOW);
  delay(100);
  digitalWrite(SOLENOID_PIN, HIGH);
  delay(100);
  pumpRunning = false;
  Serial.println("LOG: PUMP RELEASE");
}

void pump_on_off()
{
  
  turnOnPump();
  Serial.println("pump on");
  delay(2000);
  releasePump();
  Serial.println("pump release");
  delay(2000);
  shutOffPump();
  Serial.println("LOG: PUMP ONOFF");
}



void handlePump() {
  if (pumpRunning && (millis() - pumpStartTime >= pumpTimeout)) {
    shutOffPump();

    // //Transmit that the pump has been turned off
    // byte msg = build_message_byte(PUMP_CMD, 0, 0);
    // Serial.write(msg);
  }
}
void update165() {
  // Latch the inputs into the shift register
  digitalWrite(LA_PIN, LOW);
  delayMicroseconds(5);
  digitalWrite(LA_PIN, HIGH);
  delayMicroseconds(5);
}

void handleDiscDetection() {
  static byte last_data = 0;
  update165();
  byte data = SPI.transfer(0);
  data = (~data) & 0b01111111;
  //we have a rising edge
  if (data != 0 && last_data == 0) {
    Serial.print("DROP ");
    Serial.println(__builtin_ctz(data));
  }
  else if (data == 0 && last_data != 0) {
    Serial.println("LOG light renewed :)");
    char msg[40];
    sprintf(msg,"LOG prev data %d",last_data);
    Serial.println(msg);
  }
  last_data = data;
}


int bit_index(byte x) {
  // int i = 0;
  // while (x >>= 1) i++;
  // return i;

  //Like the code above, but apparently native, counts trailing zeros
  return __builtin_ctz(x);
}

// register reset button after ms_to_reset milliseconds, so user gets response more immediatly than on release.
void handleButtonPress() {
  static bool wasPressed = false;
  static unsigned long pressStart = 0;
  static bool sentStart = false;
  bool pressed = !digitalRead(BTN_PIN); // pullup defaults to high except on press.
  if (pressed && !wasPressed) 
  {
    wasPressed = true;
    pressStart = millis();
  }
  else if (!pressed)
  {
    wasPressed = false;
    sentStart = false;
  }
  else if (wasPressed && !sentStart && (millis() - pressStart) > ms_to_reset)
  {
    Serial.println("START");
    sentStart = true;
  }
}


void reset_solenoids(String stackSizes)
{
  bool customWait = false;
  if(stackSizes.length() > 0)
    customWait = true;
  for(int i=0;i<7;++i)
  {
    char msg[40];
    writeToSr(1 << i);
    int pucksToRemove = 6;
    if(customWait)
      pucksToRemove = stackSizes.substring(i,i+1).toInt(); // take the current puck stack size and apply to multiplier
    sprintf(msg,"LOG turn off solenoid %d for %d pucks", i, pucksToRemove);
    Serial.println(msg);
    delay(500 * pucksToRemove); 
  }
  writeToSr(0);
}

void open_solenoids()
{
  writeToSr(0x7f);
  Serial.println("LOG: OPEN ALL SOLENOIDS");
}


void close_solenoids()
{
  writeToSr(0);
  Serial.println("LOG: CLOSE ALL SOLENOIDS");
}

// void ack(byte msg) {
//   Serial.write(msg | (0b1 << 7));
// }
void handle_cmd(String cmd) {
  if(cmd.startsWith("RESET"))
    reset_solenoids(cmd.substring(6)); // assuming we might get RESET 3025213
  else if(cmd == "PUMP ON")
    turnOnPump();
  else if(cmd == "PUMP OFF")
    shutOffPump();
  else if(cmd == "PUMP RELEASE")
    releasePump();
  else if(cmd == "PUMP ONOFF")
    pump_on_off();
  else if (cmd == "OPEN")
    open_solenoids();
  else if (cmd == "CLOSE")
    close_solenoids();
}

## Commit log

2026-02-04 updated some coords and currently just goes to final game
2026-02-05 added smart solenoid reset, removed unnecessary time delay, started smart dirty board start
    [arduino.py, arduino_controller.ino, game.py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]
2026-03-09 added docs + updated arduino pins to reality
    [3D-BOX-007.SLDPRT, 3D-BOX-008.SLDPRT, 3D-ROB-001.SLDPRT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]
2026-03-15 removed unnecessary ack for msg + shortened path for giving puck
    [arduino.py, robot.py]
2026-03-15 added option to see current pos + up down in pucks to not kill robot
2026-03-16 added option to skip move (for puck setting). using pickup loc instead of delta.
    [robot.py, test_robot_locations.py]
2026-03-16 added fast on/off/release for pump
2026-03-16 offset from current location
2026-03-22 new pcb added
    [PCB_Robot_Led_Stripe_1.25mm_2026-03-18.dxf]
2026-03-23 updated docs and created pdfs for non-standard files
    [PCB_Robot_Led_Stripe_1.25mm_2026-03-18.dxf, חיבורים.xlsx]
2026-03-23 updated values used for ldr trimmers
    [חיבורים.xlsx]

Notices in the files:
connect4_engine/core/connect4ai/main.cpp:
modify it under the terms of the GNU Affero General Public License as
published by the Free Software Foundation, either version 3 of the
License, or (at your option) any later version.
